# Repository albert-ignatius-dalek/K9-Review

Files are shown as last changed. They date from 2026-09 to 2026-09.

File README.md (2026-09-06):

# K9 Mark 6 — Engineering Review Mirror

This is a **curated public snapshot** of milestone-quality mechanical
engineering work from the Mark 6 (K9) project — not a live development
repository. Full development history, in-progress experiments, and dead
ends stay in a private repository; only work that's reached review-ready
status lands here.

**Scope, deliberately incomplete**: mechanical engineering only. Software
architecture, the K9 personality/behavior model, and anything considered
a novel part of the project are intentionally not included here.

## Contents

- [`REVIEW.md`](REVIEW.md) — the current review request: what changed,
  open questions, known risks and unknowns.
- [`Engineering_Decisions.md`](Engineering_Decisions.md) — a running log
  of major decisions and why they were made.
- [`Design_Bible.md`](Design_Bible.md), [`Design_Standards.md`](Design_Standards.md),
  [`Hardware_Manifest.md`](Hardware_Manifest.md), [`Biomechanics_Reference.md`](Biomechanics_Reference.md)
  — the current state of the project's primary references.
- `STEP/`, `STL/` — exported geometry for the current milestone
  (Mechanical Pelvis Alpha and the three architecture candidates it
  superseded).

## How to use this if you're reviewing

Read `REVIEW.md` first — it names the specific questions this milestone
needs answered. `Engineering_Decisions.md` has the reasoning behind
anything that looks like it needs justifying. The STEP files are the
authoritative geometry; STL is provided for quick visual inspection.

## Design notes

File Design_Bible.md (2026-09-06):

# Mark 6 Design Bible

**Document priority (2026-09-06 review, [`PROJECT_AXIOMS.md`](../PROJECT_AXIOMS.md)
added above the original five as the project matured): Project Axioms,
Master Reference, Design Bible, Biomechanics Reference, Interface
Definitions (`cad/master_reference/interfaces.py`), Manufacturing
Standards (`Design_Standards.md`) — these six collectively define the
robot.**

An index, not a duplicate. Configuration-management rule for this project:
**every piece of information has exactly one canonical location.** This file
routes to that location for each topic instead of re-authoring content that
already lives somewhere else — a second copy is how a project ends up with
two answers to the same question.

| # | Section | Canonical home |
|---|---|---|
| 01 | Vision | written below (nothing else owns it); see also [`Biomechanics_Reference.md`](Biomechanics_Reference.md) (as important as this file, not subordinate to it) |
| 02 | Engineering Principles | [`Design_Standards.md`](Design_Standards.md) — "Standing engineering principles" |
| 03 | Robot Architecture | written below (nothing else owns it) |
| 04 | Dimensions | [`cad/master_reference/dimensions.py`](../cad/master_reference/dimensions.py) + [`Mark6_Master_Reference.json`](../cad/master_reference/Mark6_Master_Reference.json) |
| 05 | Interfaces | [`cad/master_reference/interfaces.py`](../cad/master_reference/interfaces.py) + [`interfaces.json`](../cad/master_reference/interfaces.json) |
| 06 | Standards | [`Design_Standards.md`](Design_Standards.md) |
| 07 | Hardware | [`Design_Standards.md`](Design_Standards.md) (servo/fastener standard) + [`BOM.md`](BOM.md) (servo/electronics inventory and placement) |
| 08 | Materials | [`Design_Standards.md`](Design_Standards.md) — "Print standard" |
| 09 | CAD Rules | [`Design_Standards.md`](Design_Standards.md) — "Naming standard" / "Revision rules"; [`README.md`](../README.md) — source-vs-generated split |
| 10 | Print Rules | [`Design_Standards.md`](Design_Standards.md) — "Print standard" |
| 11 | Assembly Rules | not yet written — no assemblies exist yet (single-module project so far) |
| 12 | Wiring Rules | not yet written as a standard; one real constraint exists in [`Hardware_Manifest.md`](Hardware_Manifest.md) (Waveshare bus driver's ~5A/header limit) |
| 13 | Maintenance Rules | [`Design_Standards.md`](Design_Standards.md) — servo standard's serviceability requirements |
| 14 | Future Expansion | written below (nothing else owns it) |
| 15 | Lessons Learned | [`TECHNICAL_DEBT.md`](../TECHNICAL_DEBT.md) for CAD/engineering; [`K9_Software_Migration_Report.md`](K9_Software_Migration_Report.md) §5 for real, quoted software lessons from the previous K9 project |
| 16 | Systems Architecture | [`Systems_Architecture.md`](Systems_Architecture.md) — the 13 robot systems, the K9 Behaviour Engine layer, hardware-to-system cross-reference |
| 17 | Software Architecture Research | [`Software_Architecture_Research.md`](Software_Architecture_Research.md) — ROS2/Nav2/SLAM/whole-body-control background, not a commitment |
| 18 | Previous Software Migration | [`K9_Software_Migration_Report.md`](K9_Software_Migration_Report.md) — full audit of the prior K9 project (voice/personality/AI/control), what migrates vs. redesigns vs. is abandoned |

---

## 01. Vision

> **The success of Mark 6 will not be measured by how many features it
> has, but by how coherent it is. Every subsystem should reinforce every
> other subsystem until the robot feels inevitable — as though it could
> not have been engineered any other way.**
>
> — ChatGPT, independent design review, 2026-09-06

**The goal is not to finish quickly. The goal is to build the best
open-source quadruped robot we can. Every subsystem should be good enough
that we'd be proud to reuse it in Mark 7.** (Jon, 2026-09-06) — this is the
standard a module is measured against before it merges to `main`, not just
"does it work."

**Core principle (2026-09-06, supersedes the earlier framing): the goal is
not a robot that *looks like* a real dog — it's a robot that *behaves*
like one. Appearance is the consequence of correct biomechanics, not a
separate target.** Mark 6 is engineering a mechanically faithful terrier
skeleton; servos, pivots, printed parts, electronics, and armour are the
engineering solution for reproducing that skeleton's function, not a
"robot" that gets styled canine afterward.

Design order (skeleton-first, not the reverse):
`canine anatomy → canine biomechanics → robot skeleton → joint locations →
motion envelopes → internal packaging → structure → armour → surface
details`. Not: pretty robot → find somewhere for the servos.

**Every joint must answer three questions before approval**: which real
canine joint does this represent? What motion does the real joint perform?
Why is this range required? A joint that can't answer these should be
reconsidered, not approved on "it works."

**Biology is the starting point, not a straitjacket** (Jon, 2026-09-06,
formalized as a project-wide directive): start from biology where it
improves function, then deliberately depart from it where hardware
requirements become insurmountable or where engineering provides a
demonstrably better solution. A departure from anatomy needs the same
justification a joint needs — state why, don't silently drift from either
biology or engineering convenience. **Biology is the reference; engineering
is the implementation** — this does not replace the established hardware
(STS3215/SCS0009 servos, two-axis hip architecture, two spine pivots,
modular PETG, U-clamp retention, serviceable cassettes, the master
reference datum system, the GitHub workflow); it governs how that hardware
gets used.

**Every subsystem answers two independent questions before it's
complete**: *Mechanical* — is this the strongest, simplest, most
serviceable implementation using our established hardware? *Biomechanical*
— would a knowledgeable observer recognize this as moving like a real
terrier? Both, not one traded for the other.

**Character direction (Jon, 2026-09-06): Mark 6 represents K9 after
thousands of years of accumulated experience. His movement is deliberate
because it reflects confidence, efficiency, and mature judgment — not
mechanical limitation. When circumstances require it, he remains fully
capable of decisive action.** Not aged or worn — exceptionally long-lived,
highly maintained, like a perfectly preserved vintage aircraft still fully
operational. His movement should read as: observe → calculate → decide →
act, not impulsive. **Behavioural rule for future gait/motion-planning
work**: default movement is calm, economical, confident, purposeful,
precise (e.g. a slow, deliberate walk up to a stop beside someone in
normal conversation); rapid acceleration and fast obstacle avoidance are
reserved for situations that genuinely demand it (e.g. an emergency/
protective response). The audience should read this as *choosing* not to
waste motion, never as *can't* move quickly. This should inform the
WALKING motion envelope's stride parameters in `cad/skeleton_study/`
once gait/software work starts — a deliberate default pace, not a
generic fast gait, with a distinct higher-speed mode for genuine need.

**Character philosophy (2026-09-06, character research): K9 is not a
dog with a computer, nor a computer pretending to be a dog — he is an
artificial person whose chosen physical embodiment is canine.** Multiple
physical Mark units have existed canonically across a consistent
personality: the body is replaceable, the character is not. He behaves
professionally, not emotionally — dependable, not cold; rarely
hesitates or apologizes; reports conclusions rather than opinions.
**Build professional priorities, not robot emotions**: owner safety →
mission → knowledge → efficiency → etiquette, with emotion as emergent
behaviour from that hierarchy, never a simulated feeling-state bolted on
separately. Humour emerges from literal interpretation and deadpan
certainty, never forced jokes. Affection is earned through action, never
sought. Voice cadence (short, precise, considered) matters more than
voice content. **Governing rule for all AI/behaviour work: Mark 6 should
never become more human — it should become more K9.** Richer perception,
better movement, and deeper understanding are means to that end, not a
drift toward generic conversational-AI behaviour. See
`docs/K9_Software_Migration_Report.md` for the full character research
and the previous K9 software project's audit this is built on.

**Candidate axiom, not yet promoted (2026-09-06) — pending scrutiny over
time before it earns a place in `PROJECT_AXIOMS.md`:**

> Mark 6 is not a robot that portrays K9; Mark 6 is an engineering
> attempt to realize K9 as a physically believable artificial being.

The distinction: not imitation, not cosplay — realization. If this
survives scrutiny, it reframes every engineering decision's actual
question from "how do we build this robot?" to "if K9 had really
existed, and we had today's engineering, what would he have been?" Left
here rather than in `PROJECT_AXIOMS.md` because that file's own change
policy requires overwhelming evidence over time, not one strong
articulation, before a statement earns axiom status.

**Final design test**: rendered in plain grey CAD with no textures, would
someone watching it move immediately think "that moves like a real dog"?
Static standing-pose appearance is not sufficient — validate in standing,
walking, trotting, sitting, lying, play bow, turning, climbing, and maximum
crouch. If a subsystem only looks right standing still, the design is
incomplete, not finished. See `cad/skeleton_study/` for the first
concrete step: a bare articulated skeleton (no armour) proving natural
standing/sitting/crouch/play-bow before armour gets rebuilt around it.

A real, manufacturable engineering project, not concept art. Appearance
target: Doctor Who K9 + modern military robotics + Boston Dynamics +
industrial machinery, reading unmistakably as a real dog (deep chest,
narrow waist, compact rear, strong shoulders, muscular thighs, digitigrade
legs) — never boxy, humanoid, skeletal, cartoonish, or over-designed. The
standing rule: **never simplify the robot because CAD is hard — improve the
engineering until it supports the approved appearance instead.** Evaluate
every decision as if preparing for commercial kit manufacture: function,
plus ease of printing, assembly, maintenance, repeatability, part
standardization, and future upgrades — closer to a Unitree/Boston-Dynamics
-grade product than a merely-functional build.

## 03. Robot Architecture

Fixed module hierarchy — no module directly modifies another, every module
attaches to `cad/master_reference/` datums instead of a neighboring module's
geometry:

```
Robot
├── Head / Neck
├── Front Torso / Mid Torso / Rear Torso
├── Spine (2 pivots, 4× STS3215)
├── Shoulders  ── Front Legs
├── Hips       ── Rear Legs        (= Mechanical Pelvis Assembly, first subsystem)
├── Tail (2× SCS0009)
├── Electronics (Jetson / battery / servo bus, removable trays)
├── Armour (segmented, removable plates)
└── Hardware (fasteners, standardized across all of the above)
```

Servo standard throughout: STS3215 (30kg/19kg tiers) for major joints,
SCS0009 for ears/tail. Load path never runs through a servo shaft — see
`Design_Standards.md`.

### Packaging architecture (ENGINEERING REVIEW 003, approved 2026-09-06)

The spine is the primary structural backbone (torsional/bending loads,
spine pivots, torso interfaces, cable trunk). Equipment is a passenger,
never structural. Each torso section owns an independent, removable
equipment cassette; nothing bridges an articulated spine joint except
flexible wiring routed through the backbone's own cable trunk (Zone C).
Suspended modules taper (wedge) toward their adjacent spine joint so they
stay outside that joint's articulation envelope — generated by sweeping the
joint's real max pitch/yaw/roll, not assumed by eye. **Blocked:** no spine
ROM (pitch/yaw/roll travel in degrees) exists anywhere in the source data
yet, so this sweep can't be generated for real until that number exists —
see `TECHNICAL_DEBT.md` TD-007.

**Design standard (verbatim, add-only, do not paraphrase):**

> All suspended equipment modules shall be attached only to their parent
> torso section. No equipment module shall span an articulated spine
> joint. Suspended modules shall conform to the articulation envelope of
> their parent section using tapered or wedge-shaped geometry where
> required.

Approved section ownership: **Front torso** — Jetson Nano, Pico, cooling,
camera interface, future USB expansion. **Middle torso** — main battery,
power distribution, voltage regulators, main fuse (lowest, below the
backbone, for CG). **Mechanical Pelvis Assembly** — rear servo controller, rear
wiring hub, tail controller, rear power distribution *only* — no Jetson or
battery volume reserved here, full stop.

Underside treatment: a faceted "keel" belly (not a flat compartment) built
from the same per-section removable trays, following the approved exterior
profile — chosen because it produces the articulation-clearing wedge shape
and the approved appearance from the same geometry, not two competing
constraints.

### Sitting posture & skeleton-first packaging (ENGINEERING DIRECTIVE 008, 2026-09-06)

**Design standard (verbatim, add-only, do not paraphrase):**

> The robot's sitting posture shall be derived from canine biomechanics
> rather than simple joint rotation. The articulated hips shall allow the
> pelvis to descend naturally between the folded rear limbs. Additional
> torso packaging volume created by this articulation shall be considered
> usable engineering volume rather than empty space.

Supersedes the earlier assumption (visible in prior concept art only, never
an engineering reference) of the torso staying suspended above folded legs.
The legs define the available anatomical volume; the torso occupies it —
design from the skeleton outward, not the other way around. See
`cad/skeleton_study/` for the articulation study this requires before the
Mechanical Pelvis Assembly is frozen.

### Core principles — see PROJECT_AXIOMS.md

The project's seven governing ideas now live in
[`PROJECT_AXIOMS.md`](../PROJECT_AXIOMS.md) at the repo root — elevated
there 2026-09-06 as irreducible, almost-never-change truths, distinct
from this file's more operational content. Not restated here to avoid
two answers to the same question. Mark 6's coherence comes from having
*fewer* governing ideas as it matures, not more — resisting an eighth
axiom unless it truly earns its place. Validate methodology before
geometry, architecture before optimization, evidence before standards.

### Decision framework: protecting the architecture (2026-09-06)

Past a certain maturity, the project stops being about "designing the
robot" and starts being about protecting an established architecture.
Every major decision should satisfy three questions:

1. **Does this preserve the established architecture?** Fits the
   biomechanics-first methodology, preserves modularity, respects the
   Master Reference.
2. **Does it improve the robot as K9?** More believable movement, better
   posture, better interaction, better character.
3. **Will this make Mark 7 easier rather than harder?** Reusable, general,
   reduces technical debt rather than adding it.

If the answer is yes to all three, it's probably right. **When two
competing solutions exist, prefer the one that simultaneously improves
biomechanics, engineering, manufacturability, and the K9 character** —
even if harder to design — over one that trades one for another. These
are the decisions that compound instead of creating trade-offs (example:
anatomically correct sitting → more packaging volume → better battery
placement → better CG → better gait → stronger character — one decision
solving six problems).

Unknowns are assets, not liabilities, at this stage: not knowing the final
battery placement, the A/B/C stiffness winner, or the exact electronics
packaging is deliberately preserved open engineering question, not a gap
to paper over with a guess before the evidence exists.

## 14. Future Expansion

Reserve mounting provision for future sensors/LiDAR/stereo cameras, a
bigger battery, an alternate Jetson or servo model, and accessory payloads
— so the chassis can evolve without a full redesign. This is a design
constraint on every module (`may_create` in that module's `interfaces.json`
entry should leave room for it), not a separate future task.

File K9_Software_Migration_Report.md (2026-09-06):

# K9 Software Migration Report

Engineering migration assessment of the previous K9 software project
("K9claw," a Pi Zero 2 WH-based project on `claw3`), produced from a
direct audit of `/home/jwh/claw3-full-backup/home/albert/K9_PROJECT/`
and related files — not a summary of intentions, an audit of what
actually exists in code.

## Three-way split (review 013)

| | Migrate | Redesign | Rebuild |
|---|---|---|---|
| **What** | Character, voice philosophy, speech rules, interaction style | Memory, Learning, Behaviour, embodied interaction | Locomotion, Balance, Navigation, whole-body control |
| **Why** | Real, mature, already converges with independent character research | Not poorly implemented — not implemented at all, so this is a clean first-principles design, not a fix | Different hardware family entirely (wheeled → legged); nothing here applies |

## Correction to the framing this assignment started from

The premise was "we've built the body, now reconnect it with the mind
that already exists." That's accurate for **one** layer and wrong for
another:

- **Character/personality**: real, reusable, worth migrating directly.
- **Body control** (motors, servos, sensors, navigation): **the previous
  project is a 4-wheeled differential-drive robot with hobby PWM servos**
  (2× via PCA9685 — head pan, tail wag), not a legged platform. It has
  zero STS3215/SCS0009 serial-bus-servo code, zero ROS, zero navigation
  implementation. There is effectively nothing here to "reconnect" to
  Mark 6's legs — Mark 6's body-control software starts from zero
  regardless of this prior work. What *does* transfer is an
  **architectural pattern** (below), not code.

## 1. Voice System

**TTS**: Piper (local neural TTS) is the live, working implementation —
generic voice (`en_GB-northern_english_male-medium`), not K9-specific
yet. An earlier `edge-tts` plan in `K9_GATE.md` was superseded before
being built — historical only.

**STT / wake word**: live code uses Google's cloud STT
(`speech_recognition` + `recognize_google`) with plain substring matching
against `["k9","k-9","kay nine","hey k9"]` — continuous transcription,
not a dedicated low-power wake-word engine. **This contradicts the
project's own architecture doc**, which specifies Whisper — a real
doc-vs-code gap, not a design decision to inherit either way.

**Voice cloning (RVC) — the most valuable unfinished asset found**: real,
substantive work targeting John Leeson's actual K9 voice. A 79-clip/9-min
Leeson dataset (demucs-separated, real audio), a real Colab training
notebook, and an informally-validated XTTS-v2 proof of concept already
run. No trained model weights exist in any local backup (they were meant
to land on a remote Oracle server not present here) — the
Piper→RVC runtime integration was never finished ("task #13" in the
project's own tracker). **~60-70% of the way to a genuinely K9-authentic
voice.**

**Real production incident, transferable as a hard requirement**: a
2026-07-06 audio feedback loop where K9 heard its own TTS output and
re-triggered itself, fixed with mutual-exclusion gating between
speak/listen. Any Mark 6 voice system needs this same gating from day
one, not as a retrofit discovered the hard way twice.

## 2. Personality

**LLM**: API-based — Anthropic Claude (`claude-haiku-4-5`) via the
`anthropic` SDK. Two generations exist: an early direct-call version and
a later design routing through a hosted "Oracle Cloud K9 brain" that
owns the persona server-side and returns a structured
`{speech, emotion, display, catchline}` payload driving voice+screen+tail
together. Role: conversation/Q&A only — no planning, no tool use, no
autonomous task execution anywhere in the codebase.

**Character definition — real, mature, worth migrating close to
verbatim.** Plain-text system prompt, consistent across both brain-server
generations:

> "You are K9, the robot dog from Doctor Who. You are an encyclopedic
> computer with dog-like loyalty and pedantic precision... Address owner
> as 'Master' or 'Mistress' always — 'Affirmative' for yes, 'Negative'
> for no, 'Insufficient data' for unknown — Begin new info with
> 'Information, Master...' or 'Suggestion, Master...' — Keep responses
> to 1-3 sentences unless asked to elaborate — Never say 'I' — say 'This
> unit' if self-reference needed."

Voice target explicitly named as John Leeson (warm, clipped, robotic
monotone) — deliberately distinct from an unrelated Dalek project's
ring-modulated voice, i.e. real care already taken to keep characters
separate. A concrete **emotion → tail angle / head pose / LED colour**
mapping already exists (5 states: happy/proud/sorrow/alert/aggression) —
a ready-made starting point for the body-language research this project
is doing.

**Memory: does not exist.** The project's own `memory/` directory is
empty. The only "memory" is an in-process 4-exchange rolling list, lost
on every restart. This is the single biggest gap in the "mind already
exists" framing — it needs to be designed fresh, not migrated.

**Decision logic**: Bosun's stated loop is ANALYSE → REPORT → ASSIST →
PROTECT. The one non-negotiable rule, enforced in code at multiple
layers (not just documented): **"VOICE IS NEVER AUTONOMOUS — K9 speaks
only on explicit command."** An autonomous "curiosity loop" was built,
found to leak past the mute flag via an unguarded wake-word path, and was
explicitly ripped out and re-gated with a single-shot arm mechanism. This
should migrate as a **hard architectural constraint**, not a preference.

## 3. Robot Control / Sensors / Navigation

**Motor/servo control**: not comparable to Mark 6 — 4× N20 DC motors via
TB6612 (differential drive, blocking duration-based commands), 2× hobby
PWM servos via PCA9685. No serial-bus-servo protocol, no closed-loop
feedback, no real-time constraints beyond `time.sleep`.

**ROS / state machine / behavior tree**: none found anywhere (grepped
project-wide). Bosun's health/self-heal loop is a decent lightweight
pattern but not a formal FSM/BT framework.

**Sensors, actual status**: IMU/environmental sensing (Sense HAT)
attempted but hardware was **never confirmed detected** — ran on mock
data. Camera attempted, **never worked** (wrong ribbon-cable size for
the Pi Zero's smaller CSI connector). Microphones/speaker: working.
LIDAR: not present in this project at all (RPLIDAR C1 only enters via
Mark 6's own, unrelated hardware manifest).

**Navigation: entirely aspirational.** No mapping, following, obstacle
avoidance, or docking code exists anywhere — only a diagram label in a
planning doc. Mark 6 starts from zero here regardless of this prior
project, not because of it.

**What actually transfers — the architectural pattern, not the code**:
independent per-subsystem microservices, each with a `/status` health
endpoint and mock-mode fallback when hardware isn't detected; a
Bosun-style conductor doing health-checks with fail-count thresholds and
per-manager restart cooldowns (a real fix for a real "restart storm" bug
where one missed health ping used to instantly restart a busy-but-healthy
manager); a Quartermaster-style passive service registry. These ideas are
hardware-independent and worth reusing regardless of legs vs. wheels.

## 4. Behaviour Patterns

**Found in the old code**: almost nothing — the audit found no idle,
greeting, following, protecting, searching, or thinking behaviours
implemented anywhere; the closest real artifact is the emotion→tail/
head/LED mapping table (§2) and Bosun's ANALYSE→REPORT→ASSIST→PROTECT
loop, which is a service-health pattern, not a character behaviour.

**New character research (2026-09-06), not derived from old code —
these are proposals to design toward, not migrated assets**:

- **Listening**: head rotates, body remains still, tail stops.
- **Waiting**: sits, observes, minimal movement.
- **Thinking**: very small head motion, eyes remain fixed, brief pause.

Confidence should dominate motion in all three — no fidgeting, no
wasted movement (consistent with the character direction already in
`docs/Design_Bible.md`: deliberate movement by choice, not limitation).
Idle, greeting, following, protecting, searching, learning, and
responding behaviours are explicitly **not yet defined** — open work for
the canonical pose/behaviour library (`docs/Biomechanics_Reference.md`).

## 4b. Character Philosophy (2026-09-06 character research)

**K9 is not a dog with a computer, nor a computer pretending to be a
dog — he is an artificial person whose chosen physical embodiment is
canine.** Canonically built by Professor Marius, with multiple physical
Mark units (I–VI now) across a consistent personality — the body is
replaceable, the character is not. This directly validates the "ancient
intelligence in a newly engineered body" framing already in the
project: the body is modern engineering; the mind carries accumulated
experience; confidence is earned, not programmed.

**K9 behaves professionally, not emotionally** — dependable, not cold.
Rarely hesitates, rarely apologizes, reports conclusions rather than
opinions. **Build professional priorities, not robot emotions**: owner
safety → mission → knowledge → efficiency → etiquette, with emotion as
emergent behaviour from that hierarchy, not a simulated feeling-state
bolted on separately.

Humour is never forced — it emerges from literal interpretation, deadpan
certainty, and perfect timing, not jokes. Affection is earned through
action, never sought. Voice cadence matters more than voice content:
short, precise, considered statements — never rambling, no filler.

**Governing rule for all future AI/behaviour work**: Mark 6 should never
become more human. It should become more K9. Richer perception, better
movement, and deeper understanding of people and the world are all
means to that end, not a drift toward generic conversational-AI
behaviour.

## 5. Lessons Learned (quoted, not paraphrased — these are process rules, not color)

- **"VOICE IS NEVER AUTONOMOUS"** — repeated verbatim across multiple
  docs, enforced at multiple code layers after an audit found a gap.
- **"Never report PASS without real observation; screen claims need
  Jon's eyes."** — don't let an AI assistant self-certify a physical
  result. Directly relevant to how physical validation should be handled
  going forward on Mark 6 (e.g. mechanism validation, print tests).
- **"Software before hardware blame — always."**
- **Config drift, named as a recurring root cause**: a display was wired
  for the wrong GPIO pins because a planning doc described different
  hardware than what actually shipped. This is exactly the discipline
  Mark 6's `Hardware_Manifest.md` KNOWN/ESTIMATED/RESERVED tagging
  already exists to prevent — treat that discipline as validated by a
  real prior failure, not just good practice in the abstract.
- A specific regression was remembered by name and guarded against
  ("don't re-apply the change that once wedged a working screen") rather
  than being at risk of repeating it.
- When a physical fix carried real risk (reseating a marginal connector),
  the user declined once for a stated reason, and the project recorded
  "do not ask again" — a real example of respecting a risk call instead
  of re-litigating it.

## 6. Migration Decision

| | Migrate directly | Needs redesign | Abandon |
|---|---|---|---|
| **Character** | System prompt + phrase rules (Master/Mistress, Affirmative/Negative/Insufficient data, "This unit," 1-3 sentences); emotion→tail/head/LED mapping table; "voice never autonomous" as a hard constraint | — | — |
| **Voice** | Speak/listen mutual-exclusion pattern; canned-soundbank + novel-TTS split; the RVC Leeson dataset + training pipeline (finish, don't rebuild) | STT (pick Whisper as originally intended, or a real wake-word engine — not continuous cloud transcription) | edge-tts placeholder plan |
| **Memory** | — | Everything — design fresh, there's nothing to preserve | — |
| **AI/reasoning** | "Fast local reflex + slower deliberate reasoning" separation of concerns (the idea, not the network topology) | — | The specific Pi-Zero/cloud-brain split (was a hardware-constraint workaround; Jetson Orin Nano 8GB doesn't have that constraint) |
| **Control architecture** | Microservice-per-subsystem pattern, health-check conductor with fail-thresholds/cooldowns, passive service registry, mock-mode-on-missing-hardware | — | — |
| **Motors/servos/sensors/nav** | — | — | All of it — different hardware family entirely, nothing here applies to STS3215/SCS0009/legs |

## What this means for the Systems Architecture

Cross-reference against `docs/Systems_Architecture.md`:
- **Character System**: has a real, strong starting point (this report's
  §2). Highest-confidence system in the whole taxonomy.
- **Speech System**: has a real, substantial, unfinished asset (Leeson
  RVC) worth prioritizing completion of, plus one hard lesson (feedback
  gating) to build in from the start.
- **Learning System**: confirmed to not exist — this is genuinely new
  work, not a migration.
- **Safety System**: inherits one real, hard-won, non-negotiable rule
  (voice-never-autonomous) as a starting requirement, not a future
  nice-to-have.
- **Locomotion/Balance/Navigation/Vision**: no prior software asset
  applies — these start from zero on Mark 6's own hardware, confirmed by
  this audit rather than assumed.

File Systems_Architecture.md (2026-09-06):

# Systems Architecture

## The Behaviour Layer — what makes hardware recognizably K9

**Not "the K9 Behaviour Engine"** (renamed 2026-09-06, review 013): a
single "Engine" implies one executable module, and this is more likely a
collection of cooperating behaviours — Attention, Conversation,
Locomotion Style, Body Language, Interaction, Task Arbitration, Idle
Behaviour, Recovery, Social Behaviour — that may never naturally collapse
into one component. **The Behaviour Layer** names the architectural
position without presupposing the implementation:

```
Character           (who K9 is — docs/Design_Bible.md, PROJECT_AXIOMS.md)
     │
Behaviour Layer      (how K9 acts it out — cooperating behaviours, not one engine)
     │
Decision Making      (owner safety → mission → knowledge → efficiency → etiquette)
     │
Robot Systems        (the 13 systems below)
     │
Hardware
```

Character sits at the top, hardware at the bottom — deliberately the
reverse of how most robotics projects evolve. The Behaviour Layer
arbitrates movement style, speech timing, attention, priorities,
interaction, posture, confidence, and curiosity across every system
below it. Whether any given cooperating behaviour ends up built as a
behaviour tree, hierarchical state machine, or planner is an
implementation detail — architecturally it's its own layer, not
something Locomotion or Speech does on their own.

**Governing rule, elevated from implementation to architecture (review
013)**: **K9 speaks intentionally, never accidentally.** The
implementation of this rule may evolve (currently: an explicit arm-gate
before any heard query reaches the brain, per
`K9_Software_Migration_Report.md` §2/§4); the rule itself should not.

**Behavioural Ethology Study** — the fourth research stream (renamed from
"Embodied Behaviour," review 013): study K9 the way an ethologist studies
an animal — catalogue Approach, Observe, Wait, Guard, Escort, Search,
Think, Follow, Recharge, Idle as behavioural specifications, not software
requirements. Not started. Result should populate
`docs/K9_Behaviour_Reference.md` (scaffolded, see below).

**Reusable behaviour states** (Behaviour-Layer-level, coordinate multiple
systems each — status: none implemented, this is the target vocabulary):
Investigate, Return Home, Follow, Guard, Observe, Escort, Search, Wait,
Greet, Patrol, Recharge, Standby, Shutdown, Wake. Supersedes the shorter
placeholder list in the Character System entry below.

---

The Hardware Manifest answers "what is this component?" This document
answers **"why does it exist?"** — every major hardware choice should
trace to at least one system below. A component that supports no system
here is a candidate for removal, not a curiosity.

**Status honesty**: most systems below are still HARDWARE-ONLY or
UNSTARTED on the software side. This is a taxonomy to organize future
work against, not a claim that Locomotion/Vision/Speech/etc. already
work. `docs/K9_Software_Migration_Report.md` (complete, 2026-09-06) has
now assessed what's real from the previous K9 software project for
Speech, Character, and Learning specifically — those three sections
below are updated accordingly; Locomotion/Balance/Navigation/Vision/
Safety/Health/Power/Thermal/Communications/Maintenance have no prior
software asset and start from zero, confirmed rather than assumed.

Each system: Purpose, Inputs, Outputs, Hardware, Software, Dependencies,
Failure modes, Future expansion — fields left TBD stay TBD rather than
being filled with plausible-sounding invention. Per the roadmap's own
Priority 1 ("do not increase detail simply because detail is possible"),
richness of the template doesn't mean every cell gets content before
the underlying architecture actually exists.

## Training vs. Learning — a distinction the project now makes explicit

- **AI Training** — large, pretrained models (speech, vision, language).
  Not something Mark 6 does; something Mark 6 *uses*.
- **Robot Learning** — specific to this physical K9: owner preferences,
  home map, daily routine, names, voice recognition, favourite locations,
  allowed rooms, charging routine, behaviour refinement. This is what
  Mark 6 should actually improve over time. See System 7 below.

## 1. Locomotion System
**Purpose**: move K9 safely and naturally.
**Inputs**: gait command, terrain state (future).
**Outputs**: joint angle targets to the servo bus.
**Hardware**: STS3215 servos, Mechanical Pelvis Assembly, spine, legs,
IMU (Waveshare Sense HAT), foot contact sensing (RESERVED, no component
selected).
**Software**: IK, gait generation, balance, recovery, slip detection,
terrain adaptation. **Status: unstarted** — the current motion-envelope
work (`cad/skeleton_study/`) is mechanical packaging, not a gait
controller. No prior software asset exists (previous K9 project was
wheeled — `K9_Software_Migration_Report.md`).
**Dependencies**: Balance System (shares IMU, cannot be validated
independently).
**Failure modes**: TBD — no controller exists to analyze yet.
**Future expansion**: TBD.

## 2. Balance System
**Purpose**: maintain stability — deliberately its own system, not folded
into Locomotion.
**Inputs**: IMU, joint encoders (none yet — servos are position-commanded,
not confirmed to report back), body orientation, foot contact (future),
battery CG.
**Outputs**: weight shift, step correction, recovery, sit recovery, fall
prevention.
**Hardware**: same IMU as Locomotion; no dedicated hardware yet.
**Software**: unstarted. Future research should target dynamic
stability, centre-of-mass estimation, and whole-body balance control —
see `docs/Software_Architecture_Research.md` for the engineering
background.
**Dependencies**: Locomotion (shares actuation), Power Distribution
(battery CG affects balance directly, per `docs/BOM.md`'s battery-
placement notes).
**Failure modes**: TBD.
**Future expansion**: TBD.

## 3. Navigation System
**Purpose**: know where K9 is.
**Hardware**: RPLIDAR C1 (RESERVED, explicitly not committed —
`Hardware_Manifest.md`), camera (RESERVED), IMU, wheel odometry (none —
legged, not wheeled), leg odometry (theoretical).
**Software**: SLAM, mapping, localization, path planning, obstacle
avoidance. **Status: confirmed zero prior asset** — the previous K9
project's navigation was "entirely aspirational... no mapping, following,
obstacle avoidance, or docking code exists anywhere" (migration report
§3). Mark 6 starts from zero here because nothing was ever built, not
because anything was discarded.
**Dependencies**: Vision (camera-based localization, if adopted).
**Failure modes**: TBD.
**Future expansion**: TBD.

## 4. Vision System
**Purpose**: understand the world.
**Hardware**: camera (RESERVED), Jetson Orin Nano 8GB (KNOWN, module/
carrier IDs confirmed).
**Software**: object recognition, people/door/furniture detection,
gesture recognition, owner recognition. **Status: no prior asset** — the
previous project's camera attempt "never worked" (wrong CSI ribbon size)
and no recognition code was found (migration report §3).
**Dependencies**: Navigation (if vision-based localization is adopted).
**Failure modes**: TBD.
**Future expansion**: TBD.

## 5. Speech System
**Hardware**: microphones (RESERVED), speaker (RESERVED).
**Software**: wake word, speech recognition, speech synthesis,
conversation.
**Status: real, substantial prior assets — assessed in
`K9_Software_Migration_Report.md` §1.** Piper TTS works (generic voice,
not K9-specific). STT is Google cloud + substring wake-word matching,
not Whisper as the old project's own docs claimed — needs a real
decision, not inherited as-is. **The John Leeson voice-cloning (RVC)
work is ~60-70% complete** (real dataset, real training pipeline,
informally validated) and should be finished, not rebuilt. One hard
requirement carries forward: speak/listen mutual-exclusion gating, after
a real 2026-07-06 audio feedback incident in the prior project.
**Dependencies**: Character System (persona drives what's said; cadence
rules apply regardless of engine).
**Failure modes**: audio feedback loop (documented prior incident,
mitigation known — mutual exclusion).
**Future expansion**: finish Piper→RVC runtime integration.

## 6. Character System
**Purpose**: preserve K9 — the one system that's not primarily hardware.
**Covers**: personality, dialogue, behaviour, decision priorities,
etiquette, humour, memory (character-facing, distinct from Robot
Learning's factual memory below).
**Status: strongest system in the whole taxonomy.** A real, mature
system prompt exists and is migrating close to verbatim (Master/
Mistress address, Affirmative/Negative/Insufficient data, "This unit,"
1-3 sentence default) — see `K9_Software_Migration_Report.md` §2 and the
Character Philosophy note in `docs/Design_Bible.md`. This prompt
independently converges with a separately-conducted character study
arriving at essentially the same K9 — two independent engineering paths
landing on the same character is real evidence the character is being
captured, not just one side's interpretation of it. Treat the prompt as
a canonical engineering asset (not immutable, but not to be casually
rewritten either).

A concrete **behavioural-mode → tail/head/LED mapping** exists as a
body-language starting point (renamed from "emotion mapping," review
013 — "Behavioural Modes" keeps the implementation aligned with K9's
professional personality rather than implying simulated feelings): the
prior project's 5 states (happy/proud/sorrow/alert/aggression) are a
first draft; a professionally-framed target set going forward is
Content/Focused/Concerned/Protective/Investigating/Mission/Idle.
Decision hierarchy: owner safety → mission → knowledge → efficiency →
etiquette (professional priorities, not simulated emotion). One
non-negotiable hard rule, elevated to architecture (review 013): **K9
speaks intentionally, never accidentally** — implementation may evolve
(currently an explicit arm-gate), the rule should not.

**Three distinct kinds of memory** (review 013's biggest structural
insight from the migration report) — keep these separate from the
start, don't let them collapse into one generic store:
- **Identity Memory** — never changes: K9, rules, character, values.
- **Long-Term Memory** — persistent: people, places, home, owner,
  experience. This is Robot Learning (System 7 below).
- **Working Memory** — temporary: conversation, current task, immediate
  observations. The prior project had only a crude 4-exchange version of
  this and nothing else — see Learning System below.
**Dependencies**: Speech (cadence/delivery), Locomotion (body language
during Listening/Waiting/Thinking states — see migration report §4).
**Failure modes**: the prior project's own near-miss — an autonomous
"curiosity loop" leaking past a mute flag via an unguarded wake-word
path. Guard against the same class of gap here, not just the same code.
**Future expansion**: see the KBE section above for the target behaviour
vocabulary (Investigate/Follow/Guard/Wait/Greet/etc.) — none implemented
yet, this is the open work.

## 7. Learning System
**Purpose**: Robot Learning specifically (see distinction above) — owner
preferences, home map, daily routine, names, voice recognition, favourite
locations, allowed rooms, charging routine, behaviour refinement.
**Status: confirmed to not exist.** The previous project's `memory/`
directory was empty; the only "memory" was a 4-exchange in-RAM rolling
list, lost on every restart (migration report §2). This is genuinely new
work, not a migration — no disk-backed store, no cross-session
persistence of anything K9 has learned exists anywhere in prior work.
**Dependencies**: Character System (what gets remembered should serve
the persona, not be a generic chat log).
**Failure modes**: TBD.
**Future expansion**: the whole system.

## 8. Safety System
**Purpose**: highest priority of all thirteen systems.
**Covers**: emergency stop, servo monitoring, temperature, battery,
collision avoidance, current limits, human safety.
**Status**: largely unstarted on the mechanical/electrical side. Real,
current exception: the Waveshare servo bus driver's ~5A per-header limit
is already a binding constraint (`Hardware_Manifest.md` TD-010) — power
must split per-tier rail, data-only sharing on the bus. Inherits one
real, hard-won software rule from the prior project: **voice is never
autonomous** (see Character System) — a safety/etiquette rule, not just
a personality trait.
**Dependencies**: Power Distribution, Character System.
**Failure modes**: TBD (mechanical); audio feedback loop and unguarded
wake-word forwarding (documented prior incidents, Speech/Character).
**Future expansion**: TBD.

## 9. Health System
**Purpose**: monitor the robot itself over time (distinct from Safety's
real-time protection).
**Covers**: servo wear, battery health, storage, cooling, motor
temperatures, system logs, predictive maintenance.
**Status: unstarted.**

## 10. Power Distribution System
**Purpose**: get the right voltage/current to every consumer safely.
**Hardware**: main battery (12V 3S2P, 5000mAh confirmed, physical dims/
connector/BMS still unmeasured — `Hardware_Manifest.md`), 2S 18650
second battery, 5A/5V bucks (ESTIMATE envelopes only), Waveshare bus
driver's ~5A/header limit (real, binding).
**Status: unstarted as a designed system** — currently a list of
components in `docs/BOM.md`, not a power architecture (no main fuse,
master switch, distribution board, current monitoring, or emergency
disconnect designed yet — Hardware Manifest §4).
**Dependencies**: Balance (battery CG), Safety (current limits),
Thermal Management (bucks/regulators generate heat).
**Failure modes**: TBD.
**Future expansion**: TBD.

## 11. Thermal Management System
**Purpose**: keep the Jetson, regulators, and servo controllers within
safe operating temperature — distinct from Health's after-the-fact
temperature *monitoring*, this is the active cooling design.
**Status: unstarted.** No fan sizing, intake/exhaust, or filter strategy
exists (Hardware Manifest §6).
**Dependencies**: Power Distribution, Vision (Jetson thermal budget
affects sustained inference).
**Failure modes**: TBD.
**Future expansion**: TBD.

## 12. Communications System
**Purpose**: wireless/networking — not investigated at all yet in this
taxonomy's prior passes.
**Status: unstarted.** No decision recorded on wireless hardware,
internal network topology, or communication buses (CAN/UART/USB/I2C/
SPI/Ethernet) — Hardware Manifest §8 lists these as open. Note: the
previous K9 software project used a Pi/cloud split over an external
network (Tailscale) purely as a hardware-constraint workaround for a
512MB Pi Zero; Mark 6's Jetson Orin Nano 8GB doesn't share that
constraint, so that specific topology should not be inherited (migration
report §2) — but the general fast-local/slow-deliberate separation of
concerns is worth keeping.
**Dependencies**: Speech (cloud STT/TTS calls, if retained), Character
(cloud-hosted persona was one prior design, not necessarily right here).
**Failure modes**: TBD.
**Future expansion**: TBD.

## 13. Maintenance System
**Purpose**: physical service procedures — distinct from Health's
condition *monitoring*, this is the human-facing servicing process
itself.
**Status: unstarted as a system**, though the mechanical design already
carries real serviceability requirements (every servo/pivot/bushing
replaceable, per `docs/Design_Standards.md`) — this system would define
the actual procedures (e.g. "to replace the left hip servo: step 1...")
once subsystems are built, per the roadmap's Acceptance Test concept.
**Dependencies**: every other system (a maintenance procedure only makes
sense once the thing being maintained exists).
**Failure modes**: TBD.
**Future expansion**: the eventual generated service manual, per
`ROADMAP.md`'s BOM-as-systems-inventory recommendation.

## Hardware → Systems cross-reference

See `docs/Hardware_Manifest.md` — each component row carries a
`Supports` tag back to the system(s) here. A component supporting no
system is a red flag, not a fact worth ignoring.

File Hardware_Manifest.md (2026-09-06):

# Hardware Manifest

Per Engineering Review 008: nothing becomes "locked" until every field
below is complete. Every component is tagged:

- **KNOWN** — purchased/fully specified, dimensions and mass verified.
- **ESTIMATED** — selected but not yet measured; datasheet/typical figures used.
- **RESERVED** — space intentionally allocated, no component selected yet.

Sources cited per row. Where this session found real prior data (searched
`/home/jwh/claw3-full-backup`, `/home/albert/old_ubuntu_keep` — actual past
project files, not guesses), it's marked "found, this session" and dated.
Where the user confirmed something directly in chat, that's cited too.

## Servos

**Supports**: Locomotion, Balance (leg/spine servos); Character (tail/
ears — body-language expression per `docs/Systems_Architecture.md` §6).

| item | status | mfr/part | qty | dims (mm) | mass | power | connector | mounting | source |
|---|---|---|---|---|---|---|---|---|---|
| STS3215 (30kg tier) | **KNOWN** | STS3215-C018 | 16 | 24.7×35.0×45.2 | 55g each | — | serial bus | U-clamp | measured, `mark6_balance.py` comment: "Jon, 2026-07-26: 19 and 30 are 55g each" |
| STS3215 (19kg tier) | **KNOWN** | (no distinct P/N found) | 8 | 24.7×35.0×45.2 (same case) | 55g each | — | serial bus | U-clamp | same as above |
| SCS0009 | **KNOWN** | FeeTech SCS0009 | 4 | 23.5×12.0×29.0 (project) / 23.2×12.1×25.25 (handoff spec — unreconciled, TD-009) | 13.2g each | — | serial bus | U-clamp | measured, same source |
| Servo inventory count found, this session | — | — | "23 base-build owned (12×STS3215-C018 19kg + 11×SCS0009) + 6×19kg-tier arrived 2026-07-22" | — | — | — | — | — | `k9quad/cad/output/SESSION_PROGRESS_20260723.md` §2 — **note this predates the current 28-servo reconciled inventory in `docs/BOM.md`; treat BOM.md as current, this row as historical provenance only** |

## Printer

| item | status | mfr/part | dims | source |
|---|---|---|---|---|
| Printer | **KNOWN, LOCKED** | FlashForge Adventurer 5M | 200×200×200mm build volume, 0.4mm nozzle | `servo_case_AD5M_CONFIRMED.gcode` embedded slicer profile — actually sliced/confirmed, not a spec-sheet guess |

## Main Battery

**Supports**: Power Distribution, Balance (CG), Thermal Management.

| item | status | mfr/part | qty | dims | mass | power | connector | source |
|---|---|---|---|---|---|---|---|---|
| Main battery | **KNOWN (spec), dimensions/connector still ESTIMATED** | 12V 3S2P Li-ion, **5000mAh** | 1 | **not measured** | ~520g\* (PROVISIONAL, engineering-report figure, predates this confirmation) | 12V nominal, runs Jetson + servo core bus | **not documented** | capacity confirmed twice: `k9quad/cad/output/SESSION_PROGRESS_20260723.md` §2 ("Jon confirmed... no new pack needed") AND directly by Jon this session (2026-09-06: "it is the 5000ma battery") — **supersedes an earlier casual "6000mAh" mention in this same session, which is now known wrong** |

**Still needed before this can move from ESTIMATED to KNOWN** (per Review
008): measured length/width/height, measured weight, connector type,
connector orientation, cable exit direction, minimum bend radius, mounting
preference, whether the pack has internal protection electronics (BMS).
`k9quad/cad/output/SESSION_PROGRESS_20260723.md` §5 flags exactly this gap
from months ago: *"Weigh the battery and read its discharge/BMS rating...
continuous amps [are the risk]... cheap 12V packs often pair a large
headline capacity with a modest BMS cutoff that trips on servo inrush."*
**This physical check was flagged as needed in July and, as far as this
search found, was never closed out.**

## Second Battery

**Supports**: Power Distribution, Balance (CG).

| item | status | dims | mass | source |
|---|---|---|---|---|
| 2S 18650 pack (7.4V mid rail) | ESTIMATED | 72×38×20mm | 100g\* | engineering report §9; `k9quad/cad/output/MARK6_COMPONENTS.md`:24 calls it "ex-Dalek" — a reused pack, not a fresh purchase |

## Compute

**Supports**: Vision, Speech, Character, Learning, Navigation
(Jetson — the shared processing node for multiple systems, not "just a
computer"); Locomotion, Balance (Pico/XIAO — real-time reflex loop);
Locomotion, Balance, Character (Waveshare bus driver — the physical
channel every servo command and body-language cue travels through).

| item | status | mfr/part | dims | power/thermal | source |
|---|---|---|---|---|---|
| Jetson | **MEDIUM CONFIDENCE** — module identified, carrier/cooling/mounting still open | **Jetson Orin Nano 8GB**, module P3767-0003, carrier board P3768-0000 | 103×90×35mm (carrier+heatsink, engineering-report estimate) | needs airflow, exact heat load not measured | module/carrier IDs found this session in `/home/albert/old_ubuntu_keep/.../.nvsdkm/hwdata/families/jetson/devices/jetson-orin-nano-8gb.json` — NVIDIA SDK Manager's own device metadata, meaning this exact module was actually flashed/set up on this machine at some point, not a guess |
| Raspberry Pi Pico | MEDIUM-HIGH — board known, packaging not frozen | RP2040/RP2350 (per engineering report §9's "legs: XIAO RP2040 or RP2350") | ~21×17.5mm (XIAO form factor, if that's the actual board) | — | engineering report §9 — **note: report's compute plan actually specifies XIAO RP2040/RP2350 and XIAO ESP32-S3 Sense, not a Pico specifically; Review 008 says "Raspberry Pi Pico" — flag this naming mismatch rather than silently picking one** |
| Servo bus interface | **KNOWN** (found this session, not in current BOM.md — gap) | 2× Waveshare "General Driver for Robots" | — | onboard UART-USB, up to 253 ST3215 servos per bus | `k9quad/cad/output/SESSION_PROGRESS_20260723.md` §2: "covered... No USB→TTL adapters need buying." **Caveat carried in that same note: bus header power path ~5A ≈ 5 non-stalled ST3215, so full-dog wiring must split power per tier rail and share data only** — a real constraint for the wiring/power-distribution unknowns in Review 008 §5. **This resolves part of Review 008's "servo controller: unknown" item** — should be reconciled into `docs/BOM.md`. |

## Sensors

**Supports**: Locomotion, Balance, Navigation (IMU — real, already
confirms the exact "not just a sensor" point from Review 008: it
supports three systems at once); Navigation (RPLIDAR C1, if committed);
Vision, Character (cameras/mics/speakers, once selected).

| item | status | source |
|---|---|---|
| IMU + barometric + temp/humidity | **KNOWN** (found this session) | Waveshare Sense HAT (Pi Zero form factor) — `SESSION_PROGRESS_20260723.md` §2: "deletes the BME280 line item AND supplies the IMU" |
| RPLIDAR C1 | **RESERVED, explicitly not committed** | same source, §6: "available, deliberately NOT committed" |
| Cameras/mics/speakers | RESERVED | no source found — open per Review 008 §7 |

## Power Distribution

**Supports**: Power Distribution System, Safety (current limits/e-stop),
Thermal Management (regulator heat).

| item | status | notes |
|---|---|---|
| Main fuse, master switch, distribution board, current monitoring, voltage regulators, emergency disconnect | **RESERVED — all open**, per Review 008 §4 | 5A buck (Jetson) and 5V buck (logic) appear in `docs/BOM.md`'s payload table as PROVISIONAL/ESTIMATE envelopes only, no board selected |

## Wiring

**Supports**: Communications, Power Distribution, Safety, Maintenance
(service loops/connector access are a servicing concern as much as an
electrical one).

Open per Review 008 §5: connector family, wire gauges, harness routing,
service loops, strain relief, connector access. **One real constraint
found this session**: the Waveshare bus driver's ~5A header limit means
per-tier power rails with shared data-only bus wiring is already a
structural requirement, not a future nice-to-have — factor this into any
future wiring standard.

## Cooling

RESERVED — all open per Review 008 §6 (Jetson, regulators, servo
controller airflow, fan sizing, intake/exhaust, filter strategy).

## Mass Distribution — the biggest open item (per Review 008 §10)

Per `docs/Weight_Budget.md`: the project's own servo mass ledger was found
to be undercounted by 246.4g this session (root-caused, not just
estimated). Every payload mass in `docs/BOM.md` is still an ESTIMATE
pending a bench weigh. **No component in this manifest has a KNOWN,
measured mass yet except the servos.** CG calculation, static stability,
and gait/pitch/roll analysis all wait on this.

## Reconciliation TODOs (found by cross-referencing old projects against current docs)

1. Update `docs/BOM.md` to include the Waveshare servo bus driver (2×
   General Driver for Robots) — currently missing entirely from the
   current BOM despite being a real, already-owned part.
2. Update `docs/BOM.md`'s IMU/BME280 line: per the 2026-07-23 note, the
   Waveshare Sense HAT supersedes the separate BME280 + IMU line items —
   current BOM still lists them separately.
3. Resolve the Pico vs. XIAO RP2040/RP2350 naming mismatch (Review 008 vs.
   engineering report) before treating either as settled.
4. Get the main battery's physical dimensions/connector/BMS status
   measured — flagged as needed in July 2026, still open as of this
   manifest.

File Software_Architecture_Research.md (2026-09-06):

# Software Architecture Research

Per the roadmap's Priority 4: architectural understanding, not
implementation commitment. Nothing here is a decision — it's the
engineering background a real decision would draw from, so that choice
happens with context instead of by default.

## ROS2 suitability

ROS2 (current stable distributions: Jazzy Jalisco, Kilted Kaiju) is the
de facto standard for exactly this class of problem — a legged platform
needing navigation, perception, and behavior coordination together. Its
real advantages for Mark 6: DDS-based networking (fits a Jetson-central,
multi-microcontroller topology cleanly), managed lifecycle nodes, and a
mature ecosystem (Nav2, MoveIt, robot_localization) that would otherwise
need building from scratch. The previous K9 software project used none
of this (confirmed by direct code audit — zero `rospy`/`ros2` references
anywhere) — its Flask-microservice-per-manager pattern is a real,
reusable *architectural idea* (health-checked services, mock-mode
fallback, a conductor with restart cooldowns) but not a ROS2 pattern.
Adopting ROS2 for Mark 6 would mean re-expressing that same idea as
ROS2 nodes/lifecycle management rather than porting Flask services
directly.

**Trade-off worth naming**: ROS2 brings real overhead (learning curve,
build system, message-passing latency) that a simpler custom framework
wouldn't have. The previous project's fast-local-reflex /
slow-deliberate-reasoning split (a microcontroller for real-time servo
control, a more capable board for reasoning) is a sound idea independent
of ROS2 — it maps naturally onto ROS2's node model, but doesn't require
it either.

## Behavior Trees

BehaviorTree.CPP is the most widely used deliberation library in the
ROS2 ecosystem, with ready ROS2 wrappers, and Nav2 itself is built on it
— since ROS2's Navigation stack switched to behavior trees as its main
customization mechanism, this isn't a competing choice against Nav2, it
composes with it directly.

**Direct fit for the K9 Behaviour Engine concept** (`docs/Systems_Architecture.md`):
a behavior tree is a natural implementation for the KBE's reusable
behaviour states (Investigate, Follow, Guard, Wait, Greet, etc.) — each
becomes a subtree, composed and reused across contexts, with the tree's
own tick-based execution model giving a clean way to interrupt a
lower-priority behavior for a higher-priority one (matching the
project's own owner-safety → mission → knowledge → efficiency →
etiquette decision hierarchy). This is architectural fit, not a
recommendation to start building — no behavior exists yet to encode.

## Navigation stack

**Nav2** (ROS2's navigation stack) is the standard reference architecture:
`slam_toolbox` or `nav2_amcl` for localization (both publish the
map→odom transform a robot needs to localize), a costmap-based planner/
controller pair, and behavior trees for task-level coordination. Mark
6's own navigation software is confirmed to be zero prior asset (the
K9 software migration report found "entirely aspirational... no mapping,
following, obstacle avoidance, or docking code exists anywhere" in the
previous project) — there's nothing to adapt, only a real architecture
to build toward once the Navigation System's hardware (camera, RPLIDAR
C1 if committed) is actually selected.

## SLAM

`slam_toolbox` is the standard ROS2 SLAM package pairing with Nav2. For
a legged platform specifically, SLAM's usual wheel-odometry input isn't
available — Mark 6 would need either leg odometry (computed from joint
angles + contact state, inherently noisier than wheel encoders) or
visual/LIDAR-inertial odometry instead. This is exactly why Balance and
Navigation are correctly modeled as separate-but-dependent systems in
`docs/Systems_Architecture.md` — the same proprioceptive data (IMU,
joint state, foot contact) that Balance needs for stability is also
Navigation's odometry source on a legged robot, unlike a wheeled one
where these are unrelated concerns.

## Locomotion framework / Whole-body control

Real, current open-source references worth knowing about, not
recommending yet: **Pinocchio** (rigid-body dynamics library — computes
the kinematics/dynamics math a locomotion controller needs), **CasADi**
(automatic differentiation + optimization, used to formulate the control
problem), and solvers like **acados** or **Fatrop** built on top. These
combine into whole-body Model Predictive Control (MPC) frameworks — the
current state of the art for quadruped locomotion — which directly
optimize joint torques through full-order inverse dynamics, unifying
motion and force planning in one predictive layer, rather than treating
gait generation and balance as separate hand-tuned stages. Example
open frameworks in this space: DWMPC (distributed whole-body MPC for
quadrupeds), BiConMP.

**Why this matters for Mark 6 specifically**: the project's own
Locomotion/Balance split (`docs/Systems_Architecture.md`) mirrors
exactly what whole-body MPC treats as one problem (motion + force +
balance, solved together) rather than two. This doesn't mean Mark 6
needs full MPC on day one — a simpler IK-plus-heuristic-balance
controller is a reasonable first step, matching the project's own
"prove the methodology before adding detail" discipline — but it means
the two systems should be designed with eventual MPC-style coupling in
mind (shared state estimation, compatible interfaces) rather than as
fully independent modules that would need re-architecting later.

## Sensor fusion / state estimation

The standard approach for legged robots: fuse IMU + joint encoder
measurements (an extended Kalman filter is the common baseline; more
recent work uses multiple leg-mounted IMUs to correct a major error
source in single-IMU proprioceptive odometry, and detects foot contact
from leg-IMU signal analysis rather than dedicated force sensors — a
cheaper alternative to Mark 6's currently-RESERVED foot contact sensing
line item). ROS2's `robot_localization` package provides a ready EKF
implementation for exactly this kind of multi-sensor fusion (IMU, joint
state, and — if adopted — GPS/visual odometry) rather than requiring a
custom filter from scratch.

**Concrete implication for Mark 6's hardware**: the servos are currently
position-commanded with no confirmed encoder feedback path
(`docs/Systems_Architecture.md`, Balance System). Real state estimation
of the kind described above needs joint position feedback, not just
commanded position — worth flagging as a real requirement to check
against the STS3215/SCS0009 servo bus protocol's actual capabilities,
not an assumption that commanded angle is good enough.

## Balance architecture

Treated as its own system deliberately (not folded into Locomotion),
consistent with how the legged-robotics literature treats it — dynamic
stability and whole-body balance control are typically designed as a
distinct control layer, informed by the same state estimate Navigation
uses, feeding correction back into the same joint commands Locomotion
issues. See "Locomotion framework" above for how MPC unifies this in
current research; the practical starting point for Mark 6 is simpler:
real IMU-based orientation feedback plus centre-of-mass estimation from
`docs/BOM.md`'s (still largely ESTIMATED) mass distribution, before any
MPC-level sophistication.

## What this does NOT decide

No commitment to ROS2, Nav2, any specific MPC framework, or a timeline.
This is background for whenever Locomotion/Balance/Navigation actually
start (roadmap Priority 1 is Mechanical Pelvis completion; these systems
come later, per the outside-in working order). Revisit this document
when that work actually starts, rather than treating it as a spec
written too early.

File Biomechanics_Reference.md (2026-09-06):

# Biomechanics Reference

Per the Canine Biomechanics Study Programme (2026-09-06): as important a
document as `Design_Bible.md`, not a subordinate one. Mark 6 is designed
from motion — every external shape should exist because the underlying
biomechanics require it, not the reverse.

**Status: scaffold only.** The research itself (veterinary gait resources,
kinematic studies, real-terrier video references, motion-capture data) is
coming from a dedicated ChatGPT study — this file defines the structure it
lands in, so each behaviour has one canonical place from day one rather
than being retrofitted into shape later.

## Per-behaviour entry template

```markdown
### <Behaviour name>

**Video references**: side / front / rear / top (if available)

**Mechanical observation**: what the dog is actually doing, mechanically
(e.g. "sitting: pelvis rotates rearward, femurs rotate forward and
abduct, stifles fold tightly, hocks fold underneath, body descends
between the legs, rear of pelvis becomes the support point").

**Affected joints**: which joints move, and how much (ROM, not just
direction).

**Engineering translation**: what functional requirement this creates for
Mark 6's hardware (e.g. "requires the hip ab/adduction axis to
contribute to sitting, not just the pitch axis").

**Packaging implications**: what volume this behaviour occupies/frees,
and where (feeds `cad/skeleton_study/motion_envelopes.py`).

**Structural implications**: what this demands of load paths /
serviceability / part boundaries.

**Collision implications**: what this behaviour must stay clear of
(other limbs, torso, ground, tail).

**Visual implications**: what this contributes to reading as
"authentically canine" per the Design Bible's final design test.
```

## Canonical motion set (per the study programme — target coverage)

Neutral stand · Relaxed stand · Walk · Trot · Slow approach · Stop · Sit ·
Lie · Play bow · Turn · Look around · Step over obstacle · Climb step ·
Sniff ground · Wait · Tail wag · Greeting

**Coverage so far**: Standing (`cad/skeleton_study/leg_kinematics.py`,
validated against real locked data), Sitting (`cad/skeleton_study/poses.py`,
PROPOSED target posture — see `TECHNICAL_DEBT.md` TD-008), Walking
(`cad/skeleton_study/motion_envelopes.py`, a PROPOSED ±20° stride sweep,
explicitly not real gait data). Everything else on the canonical list is
not yet started.

## Methodology: pose-driven, not angle-driven (2026-09-06)

Mark 6 is not anatomically identical to a terrier — different joint
locations, link proportions, and actuator arrangement mean copying real
canine joint angles verbatim can produce a *less* believable posture, not
a more accurate one. The terrier biomechanics study is therefore a
**pose reference**, not an angle reference:

```
Desired canine posture → Inverse kinematics → Joint angles → Validate against hardware limits
```

`cad/skeleton_study/poses.py`'s current sitting pose was built the
simpler way (hand-picked joint angles, not solved by IK from a target
posture) — a reasonable first pass, but the canonical pose library (see
below) should move to real IK once it's built out.

## How this feeds the CAD

Every entry here should be traceable to a concrete artifact:
`cad/skeleton_study/envelope_<behaviour>.stl` (the swept occupied-space
volume) and, once real target angles exist for that behaviour, an update
to `leg_kinematics.py`/`motion_envelopes.py`'s pose parameters. A
behaviour entry with no corresponding envelope file is documented but not
yet engineered — don't let this file get ahead of the CAD it's supposed to
justify.

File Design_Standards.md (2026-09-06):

# Mark 6 Design Standards

The project "constitution." Every module (Mechanical Pelvis Assembly first) must
comply. When a new part needs something not covered here, propose an
addition here rather than making a one-off local choice — see
`ECR_Process.md` if the addition would also require changing a locked
datum in `cad/master_reference/`.

## Servo standard

- **STS3215 class** (30kg and 19kg tiers, same case: 24.7×35.0×45.2mm) for
  all major joints; **FeeTech SCS0009** (23.5×12.0×29.0mm project-measured)
  for ears and tail.
- Integrated saddle + **removable heavy-duty U-clamp** retains the servo.
- **The servo is never the structural bearing.** Load path rule: if the
  answer to "where does this load go" is "through the servo," redesign the
  joint. Loads travel through printed pivots (trunnions/bushings); the servo
  only supplies torque, ideally via a broad drive flange/link, not a
  cantilevered horn tab.
- Every servo must be replaceable via one panel + a few screws — never by
  dismantling head/neck/torso/battery/electronics first.

## Pivot standard

- Large printed pivot pins, replaceable bushings, broad bearing surfaces,
  large fillets. Avoid tiny shafts carrying bending loads.
- Current rear-hip approach (PROVISIONAL, ChatGPT handoff): print-in-place
  fixed trunnion + captive sleeve. Ø16mm axle preferred, Ø14mm fallback,
  0.25–0.30mm radial clearance. No bearing, no separate steel axle needed.
- Hip system architecture: **PREFERRED, not LOCKED** (downgraded
  2026-09-06 — do not freeze until the actual mechanism is developed and
  physically validated). Working intuition: primary structural pivot →
  bearing support → sidestep axis → frontstep axis, upper servo mounted
  above/lower below, structural pivots independent of servo output shaft,
  modular rotate-to-service cassette. Shoulders would reuse this language
  once it's actually locked. Decide the real orientation from: shortest
  load path, bearing placement, serviceability, cable routing,
  printability, CG, and servo-output-bearing side-load — not from
  guessing a box orientation in a volume reservation (which is exactly
  what `cad/mechanical_pelvis/pelvis_alpha.py`'s servo envelope currently
  does, flagged there as a first guess).

## Fastener standard

- **M3 through-bolts + captured nuts**, project-wide. Avoid threaded
  plastic where practical. No heat-set inserts, threaded rod, or bearings
  currently in use anywhere in the project — introducing one is a new
  decision, not a continuation of anything already standardized.
- Brass-tube joints (legacy leg construction): 3× Ø3.35×12mm socket
  triangle, Ø3.0mm OD brass tube, running-clearance fit (not press fit).

## Clearance standard

- General PETG clearance: to be established from a physical test coupon on
  the Adventurer 5M (no PETG-specific clearance figure exists yet — the
  legacy `CLR_POCKET=0.25mm` figure was tuned for resin/MSLA, not FDM PETG.
  Don't reuse it un-verified).
- Hot-servo air gap (STS3215 runs 50–70°C under load): resin-era design used
  `AIRGAP=1.2mm` between case and material — re-verify this figure for
  PETG's higher heat tolerance rather than assuming it still applies as-is.
- Standardized tolerances live in **one** config (this project's
  `cad/master_reference/dimensions.py` for datums; a future
  `cad/*/clearances.py` for print-specific tolerances) — no per-part
  guessing.

## Print standard

- **Printer: FlashForge Adventurer 5M (FDM).**
- **Material: PLA / Strong-PLA for prototyping now; PETG for final parts**,
  once a design is physically confirmed on PLA first (Jon, 2026-09-06).
- No trapped supports, minimal support, self-supporting overhangs where
  possible, large fillets, consistent clearances, flat print surfaces.
- No print-in-place *structural* joints (the hip trunnion/sleeve is the one
  explicitly approved exception, since its whole point is print-in-place).
- Every servo must remain removable without damaging the print.
- Every part should state: print orientation, support requirement,
  estimated print time/weight, infill, wall count (per master-brief
  principle #3) — track this per-part once real STLs exist under `stl/`.

## Volume-first generation (2026-09-06, review 006/007 — permanent standard)

For any subsystem sharing space with a moving part (a limb, a spine
pivot, anything with a real motion envelope):

```
Available Structural Volume =
    Body Volume
    − Motion Envelope
    − Bearing Envelope
    − Servo Envelope
```

Generate structure *within* this volume (verified by boolean
intersection, a geometric guarantee) rather than authoring a shape and
checking it against the envelope afterward. Proven on the Mechanical
Pelvis Alpha (`cad/mechanical_pelvis/PELVIS_ALPHA.md`): identical
structural geometry to an author-then-check candidate, but measurably
less motion-envelope intrusion (28.7cm³ vs. 54.6/37.2/43.3cm³) purely from
generation order. Apply the same 5-step method to future subsystems that
share space with moving parts (shoulders, ribcage, neck, head, tail base):
define motion → generate motion envelope → reserve hardware → generate
allowable volume → design within it.

## Functional vs. character geometry (2026-09-06)

Every geometric feature is one of two kinds, and neither should compromise
the other:

- **Functional geometry** — load paths, articulation, mounting,
  serviceability, manufacturing. Governed by engineering (this document,
  the Master Reference, the volume-first method above).
- **Character geometry** — silhouette, visual identity, posture, K9
  recognition. Governed by the Character Definition
  (`docs/Design_Bible.md`'s Vision/Character sections).

A feature that can't be classified as one or the other, or that quietly
serves neither, should be questioned before it's added.

## Engineering zones (Jon, 2026-09-06)

Every module's internal structure separates into three zones. **Never allow
these to mix** — a wiring channel cut through a primary load-bearing wall,
or a servo boss doubling as a structural rib, is a design error, not a
style choice. This is what makes servicing tractable as the robot grows.

| Zone | Purpose | Owns |
|---|---|---|
| **A — Structural** | load paths only | shells, ribs, fillets, torque boxes |
| **B — Mechanical** | servos, pivots, bushings, maintenance | brackets, saddles, U-clamps, bushings, trunnions |
| **C — Utilities** | wiring, connectors, future sensors | wire channels, connector mounts |

Each module's `interfaces.json` entry states which of its `may_create` items
belong to which zone (see the `mechanical_pelvis_assembly` entry for the first example).
Adding a new zone-crossing feature to any module needs a documented reason,
not a shortcut.

## Naming standard

- Datum names (used in `dimensions.py`, `interfaces.json`, and every STEP
  label) are lowercase snake_case, mirrored joints suffixed `_L`/`_R`
  (e.g. `hip_L`, `shoulder_R`), stations prefixed `station:` (e.g.
  `station:S0-pelvis`).
- CAD source files: one module = one folder under `cad/`, named after the
  module (`cad/mechanical_pelvis/`, not `cad/MechanicalPelvis/` or a version-numbered
  variant).
- **No `_Final_Final_v3`-style files.** One source of truth per module; use
  git history and tags for versions, not filename suffixes.

## Revision / documentation rules

- Every value in `dimensions.py` (and any future per-module dimension file)
  carries a status tag: **LOCKED / ADOPTED / PROVISIONAL / PROPOSED / OPEN**
  (definitions in `cad/master_reference/Mark6_Master_Reference.md`). Never
  silently resolve a conflict between two tagged sources — state both and
  flag it.
- Changing a LOCKED datum requires an ECR (`docs/ECR_Process.md`), not a
  direct edit.
- Per-part documentation (once parts exist): purpose, version, weight,
  print orientation, material, hardware, assembly notes, known issues.

## Standing engineering principles (carried from the 2026-09-05 master brief)

Load path over servo · real anatomy sources joint locations · printing-first
· one-panel serviceability · fastener standardization · one design language
across shoulders/hips/legs/head · minimize unique parts, mirror L/R ·
weight distribution (battery lowest, compute central, head/tail lightest) ·
collision-check every revision · fully parametric (nothing hard-coded) ·
never solve a problem twice · print small before printing big · automatic
mass/print-time/CoM estimation per part · one tolerance config, referenced
everywhere · fixed module hierarchy, no module directly modifies another ·
one master assembly, no version-suffix files · stress-analysis reasoning
required on structural parts · cost tracking per revision · design as a
platform (reserve provision for future sensors/battery/compute upgrades).

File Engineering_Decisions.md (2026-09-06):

# Engineering Decisions Log

## 2026-09-06 — Mechanical Pelvis Alpha validated a *methodology*, not a part

**Decision**: Alpha is not "version 1" of the production pelvis — it's
**Proof of Method**. Its job was to prove generated-within-the-bound
geometry beats author-then-check geometry, which it did: 28.7 cm³ motion-
envelope intrusion vs. 54.6/37.2/43.3 cm³ for the three authored
candidates, using identical structural geometry to Candidate A.

**Follow-up analysis, not just the headline number**: the residual 28.7
cm³ was classified by feature rather than accepted as a single figure —
10.7 cm³ from the general shell (only right where it connects to the hip
boss), 21.4 cm³ from the hip boss/bearing/servo mount itself, 0.0 cm³
from the spine clevis. ~100% Structural/Bearing/Servo, 0% Incidental. The
success criterion is minimizing *non-essential* intrusion, not intrusion
itself — by that standard this Alpha has reached its engineering floor
for the current feature set.

**Next milestone — Methodology Replication**: apply the same 5-step
volume-first method to the shoulder assembly, ribcage, and neck. If it
reproduces similar packaging gains on each, the project has validated an
engineering *process*, not just one part.

A running record of major decisions and why they were made — curated from
the private engineering history, not a full transcript.

## 2026-09-06 — Volume-first generation replaces author-then-check

**Decision**: structure for any subsystem sharing space with a moving
part is generated by boolean intersection with a validated motion
envelope, not authored freely and checked against one afterward.

**Why**: three hand-authored pelvis candidates (torque box, semi-
monocoque, space-frame) all intruded into the real sitting-pose leg
envelope (32.9k–50.7k mm³). Rather than trim material reactively, the
workflow inverted: `Body Volume − Motion Envelope − Bearing Envelope −
Servo Envelope = Available Structural Volume`, and structure is generated
inside that bound. Validated on Mechanical Pelvis Alpha: identical
structural shape to Candidate A, but 28.7 cm³ of envelope intrusion vs.
54.6 cm³ — the improvement is attributable to generation order alone.

## 2026-09-06 — Rear Drive Module renamed to Mechanical Pelvis Assembly

**Why**: "Rear Drive Module" frames the subsystem around motors and
structure. "Mechanical Pelvis" frames it around anatomy, movement,
packaging, and structure simultaneously — the renaming is meant to keep
anatomy-first thinking the default, not a cosmetic change.

## 2026-09-06 — Sitting posture is a design choice, not a biology lookup

**Why**: Mark 6 is not anatomically identical to a dog, so exact canine
joint-angle replication isn't the objective. The method is: define the
desired posture, then solve the mechanism backward — bounded by passive
biological safety-stop limits (never commanded to the limit itself), not
derived from them.

## 2026-09-06 — Candidate C (space-frame) stays under consideration

**Why**: it has the lowest total material of the three candidates for a
similar motion-envelope intrusion. It lacks a working stiffness
evaluation method (Bredt-Batho's closed-thin-wall theory doesn't apply to
an open space-frame), but a missing evaluation method is not the same as
a bad architecture — it stays open pending a method that actually fits
the topology.

## 2026-09-06 — Character direction: deliberate movement, not mechanical limitation

**Decision**: Mark 6 represents K9 after thousands of years of
accumulated experience — calm, economical, purposeful movement by choice,
with full capability for rapid decisive action when genuinely needed.
Not aged or worn down. This is a standing constraint on future
gait/motion-planning work, not just a narrative note.

## 2026-09-06 — Battery capacity confirmed at 5000mAh

**Why**: an earlier informal mention of "6000mAh" was superseded by
direct confirmation, consistent with a 2026-07-23 project log ("12V 3S2P
5000mAh Li-ion, Jon confirmed"). Physical dimensions, connector, and BMS
status remain unmeasured — the spec being confirmed doesn't mean the
part is fully characterized yet.

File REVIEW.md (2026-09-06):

# REVIEW REQUEST #1 — Mechanical Pelvis Alpha

**Milestone**: first structure generated *within* a validated motion
envelope, rather than authored freely and checked against one afterward.

## Files changed (this snapshot)

- `STL/Mechanical_Pelvis_Alpha_v1.stl` — the new Alpha geometry
- `STL/Manufacturable_Structural_Core.stl` — the allowed-volume bound
  Alpha was generated inside
- `STEP/Candidate_A_TorqueBox.step`, `Candidate_B_SemiMonocoque.step`,
  `Candidate_C_SpaceFrame.step` — the three prior candidates Alpha's
  approach is compared against
- `STEP/Mark6_Master_Reference.step` — the datum skeleton everything else
  is built from
- `Hardware_Manifest.md`, `Biomechanics_Reference.md` — new this
  milestone (see `Engineering_Decisions.md` for why)

## Headline result

| | intrusion into the sitting-pose motion envelope |
|---|---|
| Candidate A — torque box | 54.6 cm³ |
| Candidate B — semi-monocoque | 37.2 cm³ |
| Candidate C — space-frame | 43.3 cm³ |
| **Alpha (generated within the bound)** | **28.7 cm³** |

Alpha uses the *same* structural shape as Candidate A (same loft, same
wall thickness) — the improvement comes entirely from generation order
(intersect with the allowed volume before adding hardware features,
rather than checking afterward), not from a cleverer shape.

## Questions for review

1. Is 28.7 cm³ of residual intrusion (from the hip bosses/spine clevis
   legitimately reaching toward the hip axis) an acceptable floor, or
   does the hardware-mounting geometry itself need rethinking?
2. Candidate C remains under consideration but has no stiffness
   evaluation yet (Bredt-Batho doesn't fit its topology) — what method
   should replace it?
3. Sitting/lying/crouch/play-bow angles are currently a design choice
   (a target posture, not a biomechanical replication) — does the
   incoming terrier biomechanics study change any of the current
   PROPOSED sitting-pose angles?

## Known risks

- Alpha is a mesh-boolean result, not reconstructed parametric CAD — no
  STEP export exists for it yet.
- Servo box orientation in the reserved envelope is a first guess, not
  the finalized stacked sidestep+frontstep arrangement.
- No fastener clearance reservation yet (no real bolt layout exists).

## Unknowns (see `Hardware_Manifest.md` for the full list)

- Main battery physical dimensions/connector/BMS status — capacity
  confirmed (12V 3S2P 5000mAh), everything else still needs measuring.
- Front-leg motion envelope not yet built (hind leg only so far).
- Lying/crouch/play-bow motion envelopes not yet built (standing/walking/
  sitting only).

Please review.

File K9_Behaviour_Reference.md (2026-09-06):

# K9 Behaviour Reference

Not implementation. Behaviour. Per review 013: every subsystem eventually
references this document — it specifies *what K9 does*, independent of
whether the Behaviour Layer ends up implementing it as a behaviour tree,
state machine, or planner.

**Status: scaffold only.** The Behavioural Ethology Study (the renamed
4th research stream — study K9 the way an ethologist studies an animal,
not the way a software project specs a feature) hasn't started. This
file defines the structure it lands in.

## Per-behaviour entry template

```markdown
### <Behaviour name>

**Purpose**: why this behaviour exists.
**Trigger**: what causes K9 to enter this behaviour.
**Body posture**: overall stance/orientation.
**Head posture**: where attention is directed.
**Tail**: position/motion.
**Voice**: does K9 speak during this behaviour, and how.
**Speech style**: cadence/formality specific to this behaviour, if
different from baseline.
**Priority**: where this sits in the owner-safety → mission → knowledge →
efficiency → etiquette hierarchy.
**Interruptibility**: what can pre-empt this behaviour, and what can't.
**Exit condition**: what ends the behaviour and what happens next.
```

## Target behaviour vocabulary (not yet specified — names only)

Investigate, Return Home, Follow, Guard, Observe, Escort, Search, Wait,
Greet, Patrol, Recharge, Standby, Shutdown, Wake — see
`docs/Systems_Architecture.md`'s Behaviour Layer section for where these
sit architecturally. Also from the ethology framing specifically:
Approach, Think.

## Relationship to other documents

- `docs/Biomechanics_Reference.md` — the physical motion each behaviour
  requires (a behaviour's "Body posture"/"Head posture" fields should
  cite real poses from there once both exist, not invent new ones).
- `docs/Design_Bible.md` — the character philosophy each behaviour must
  stay consistent with (professional priorities, not simulated emotion;
  more K9, never more human).
- `docs/Systems_Architecture.md` — which of the 13 systems a given
  behaviour actually coordinates (a behaviour with no system dependency
  isn't really a robot behaviour).

A behaviour specified here with no corresponding motion study or system
dependency is documented but not yet engineered — the same discipline
`Biomechanics_Reference.md` already applies to itself.

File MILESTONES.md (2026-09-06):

# Milestones

Traceability log — one entry per export from the private engineering
repo. Each entry names the private repo's commit this snapshot came from,
so "what changed since last time" is always answerable without diffing
STEP files by eye.

| version | date | headline | private repo commit |
|---|---|---|---|
| v1 | 2026-09-06 | Mechanical Pelvis Alpha — first structure generated within a validated motion envelope (28.7 cm³ intrusion vs. 54.6/37.2/43.3 cm³ for the three authored candidates) | `52bb147` (branch `rear-drive`) |
| v2 | 2026-09-06 | Alpha reframed as Proof of Method -- intrusion classified by feature (~100% Structural/Bearing/Servo, 0% Incidental); PR #1 merge gate formalized; 7 core principles locked | `55cd017` (branch `rear-drive`) |

| v3 | 2026-09-06 | Systems Architecture (13 systems + K9 Behaviour Engine) and full K9 software migration audit -- previous project confirmed as an unrelated wheeled platform; Character/personality migrates directly, body-control software does not | `6a1029f` (branch `rear-drive`) |

| v4 | 2026-09-06 | Review 013 refinements: Behaviour Layer (not Engine), Behavioural Modes, three memory types, candidate axiom preserved pending scrutiny | `ee0a4e7` (branch `rear-drive`) |

## Convention for future exports

A commit in the private repo becomes export-worthy when it's tagged with
a headline — a one-line summary written for an external reviewer, not an
internal commit-message detail. Only tagged commits get mirrored here;
everything else (in-progress experiments, dead ends, routine fixes) stays
private by default. This keeps curation a deliberate act, not something
a cron job infers from commit volume or file changes.

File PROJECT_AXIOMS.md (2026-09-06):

# Project Axioms

## Purpose

The irreducible philosophical foundation of the Mark series. Not
standards (`docs/Design_Standards.md` — how ideas get implemented). Not
engineering decisions (`Engineering_Decisions.md` — a log of specific
choices and why). Just the truths everything else is built on.

```
PROJECT_AXIOMS.md   — what truths define Mark 6?
        │ defines
        ▼
Design_Bible.md      — given those axioms, how do we design Mark 6?
        │ implements
        ▼
Design_Standards.md  — exactly how do we implement those ideas?
        │ constrains
        ▼
Subsystem documents
```

## Seven Axioms

1. We are building the actual K9 character using modern engineering.
2. Movement creates appearance.
3. Biomechanics define allowable structure.
4. Geometry is generated from validated constraints.
5. Biology informs behaviour. Engineering implements behaviour.
6. Protect the architecture.
7. Every subsystem should simplify the next subsystem.

## Change Policy

These axioms represent the philosophical foundation of the Mark series.
They should only be modified when overwhelming engineering evidence
demonstrates that an axiom no longer serves the project's purpose. New
axioms should be added only if they are fundamental, broadly applicable,
and cannot be derived from the existing set.

## Revision History

- **2026-09-06** — formalized, at the point the project's engineering
  philosophy stabilized (independent design review's "Architectural
  Stability Phase 1" — the philosophy and methodology becoming internally
  consistent, not the robot nearing completion). Moved out of
  `docs/Design_Bible.md`'s "Core principles" section rather than
  duplicated there, per this project's own configuration-management rule.

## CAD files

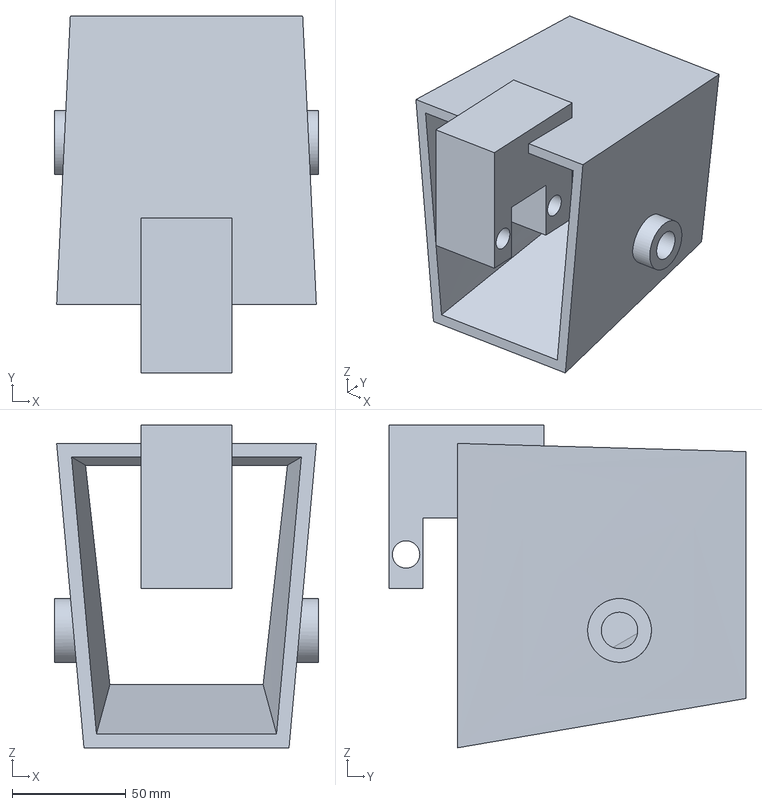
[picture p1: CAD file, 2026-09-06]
STEP/Candidate_A_TorqueBox.step
116.0 x 156.7 x 141.6 mm

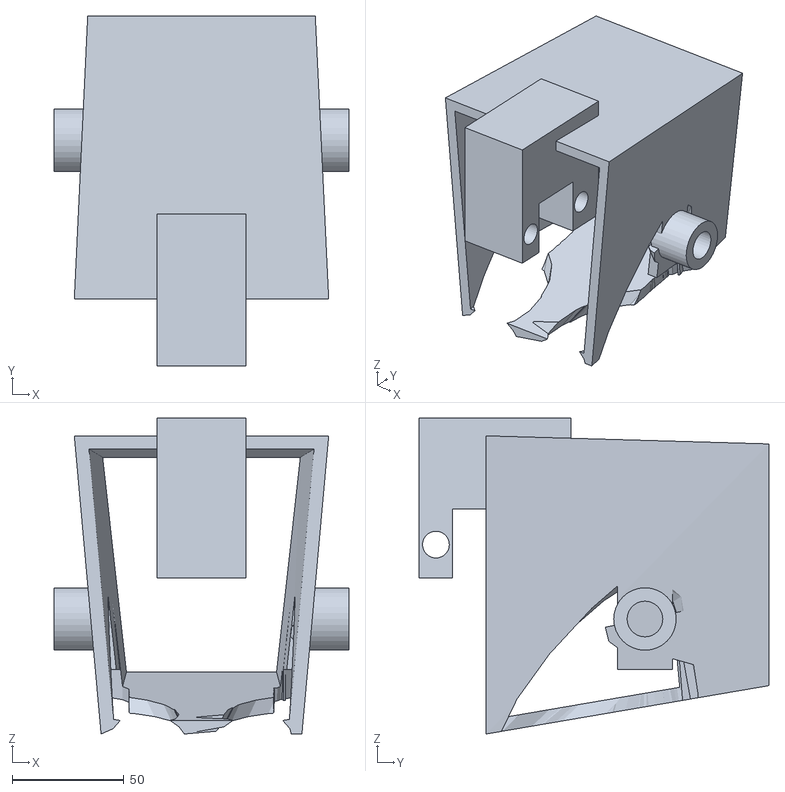
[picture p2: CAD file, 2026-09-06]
STL/Mechanical_Pelvis_Alpha_v1.stl
132.0 x 156.7 x 141.6

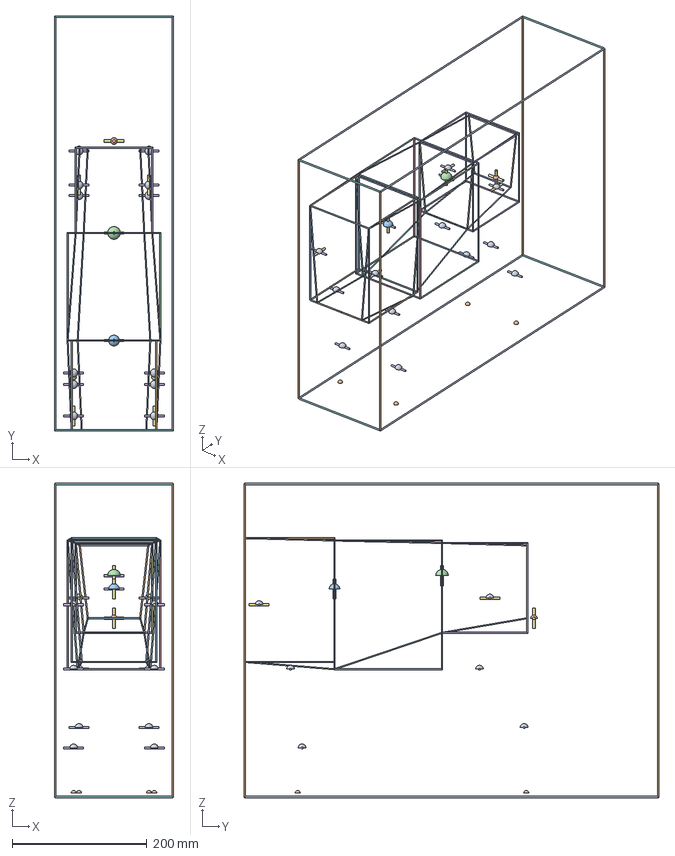
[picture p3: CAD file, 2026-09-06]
STEP/Mark6_Master_Reference.step
177.6 x 617.1 x 467.9 mm
0000_shoulder_R
0001_shoulder_L
0002_elbow_R
0003_elbow_L
0004_carpus_R
0005_carpus_L
0006_ffoot_R
0007_ffoot_L
0008_hip_R
0009_hip_L
0010_stifle_R
0011_stifle_L
0012_hock_R
0013_hock_L
0014_hfoot_R
0015_hfoot_L
0016_spine_aft_pivot
0017_spine_fwd_pivot
0018_rear_spine_clevis
0019_tail_base
0020_shoulder_pitch_(flexion-extension)
0021_shoulder_pitch_(flexion-extension)
0022_shoulder_ab-adduction_(sidestep)
0023_shoulder_ab-adduction_(sidestep)
0024_elbow_flexion-extension
0025_elbow_flexion-extension
0026_carpus_flexion-extension
0027_carpus_flexion-extension
0028_hip_FRONTSTEP_--_pitch_(fwd-back)
0029_hip_FRONTSTEP_--_pitch_(fwd-back)
0030_hip_SIDESTEP_--_ab-adduction_(left-right)
0031_hip_SIDESTEP_--_ab-adduction_(left-right)
0032_stifle_flexion-extension
0033_stifle_flexion-extension
0034_hock_flexion-extension
0035_hock_flexion-extension
0036_spine_aft_pivot_pitch
0037_spine_aft_pivot_yaw_(nominal_2nd_axis)
0038_spine_fwd_pivot_pitch
0039_spine_fwd_pivot_yaw_(nominal_2nd_axis)
0040_tail_base_WAG_--_left-right
0041_tail_base_LIFT_--_up-down
0042_station_S3-forechest
0043_station_S3-forechest
0044_station_S3-forechest
0045_station_S3-forechest
0046_station_S2-rib
0047_station_S2-rib
0048_station_S2-rib
0049_station_S2-rib
0050_station_S1-waist
0051_station_S1-waist
0052_station_S1-waist
0053_station_S1-waist
0054_station_S0-pelvis
0055_station_S0-pelvis
0056_station_S0-pelvis
0057_station_S0-pelvis
0058_envelope_longeron_UL
0059_envelope_longeron_UL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

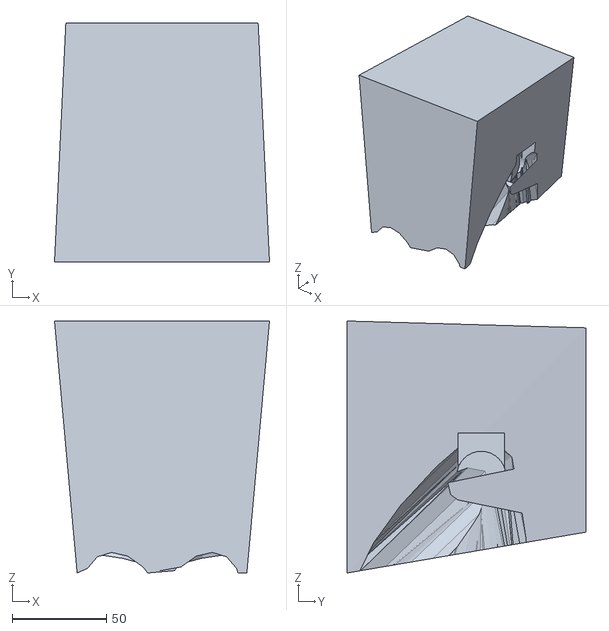
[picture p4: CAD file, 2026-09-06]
STL/Manufacturable_Structural_Core.stl
114.0 x 126.7 x 133.6

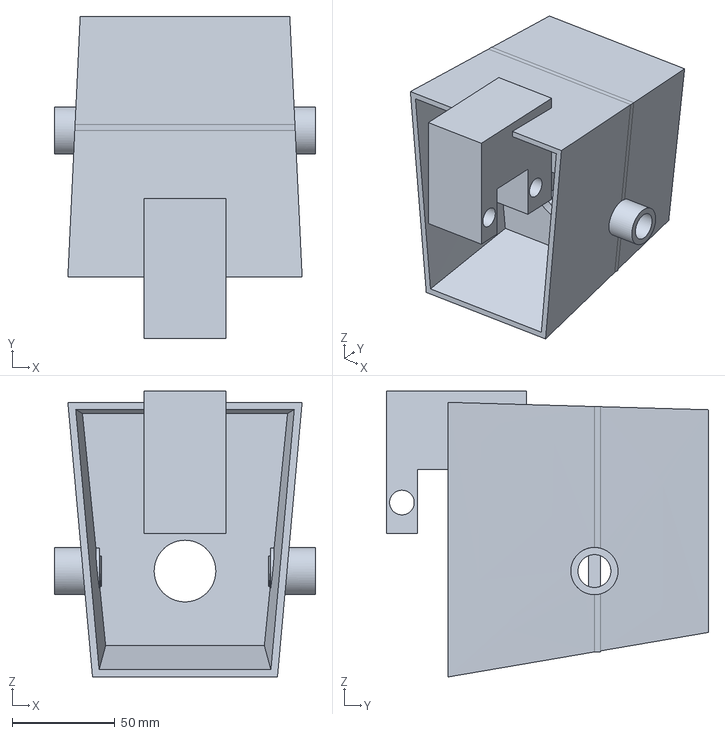
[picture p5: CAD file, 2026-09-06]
STEP/Candidate_B_SemiMonocoque.step
127.0 x 156.7 x 139.1 mm

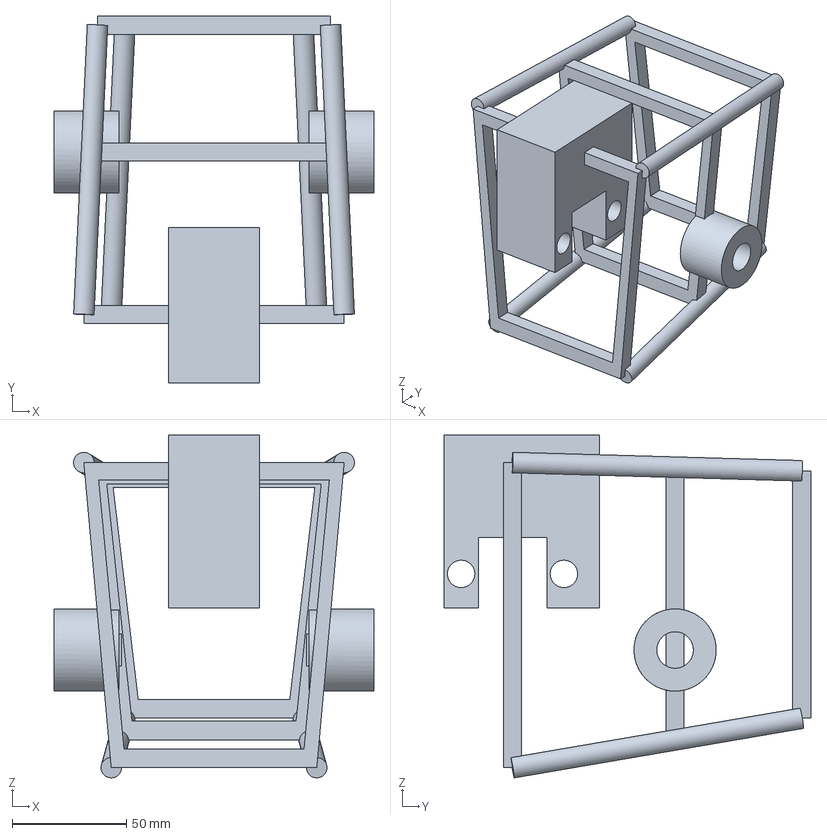
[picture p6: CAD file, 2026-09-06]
STEP/Candidate_C_SpaceFrame.step
140.0 x 160.7 x 150.0 mm

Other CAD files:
STL/Candidate_A_TorqueBox.stl
STL/Candidate_B_SemiMonocoque.stl
STL/Candidate_C_SpaceFrame.stl
STL/Mark6_Master_Reference.stl

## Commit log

2026-09-06 Milestone snapshot: Mechanical Pelvis Alpha
    First public review-mirror snapshot. See REVIEW.md for the current
    review request and Engineering_Decisions.md for the reasoning log.
    Claude-Session: https://claude.ai/code/session_016YjeskGBFavEQc8VWgFvuM
    [Candidate_A_TorqueBox.step, Candidate_A_TorqueBox.stl, Candidate_B_SemiMonocoque.step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]
2026-09-06 Add MILESTONES.md traceability log
